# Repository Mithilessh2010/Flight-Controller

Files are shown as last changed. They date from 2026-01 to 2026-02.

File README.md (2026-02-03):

# Rocket Flight Controller

## What This Board Does

This flight controller handles the main electronics:

- Controls servos (for fins or thrust vector control)
- Measures movement and rotation with an IMU
- Measures altitude using a pressure sensor
- Logs flight data to a microSD card
- Uses USB-C for programming and power
- Charges a 2-cell LiPo battery
- Provides stable 5V and 3.3V power

---

## Main Parts Used

- **Microcontroller:** STM32F722RET6  
- **IMU:** ICM-45686 (SPI)  
- **Pressure Sensor:** BMP580 (I2C)  
- **Storage:** microSD card (SDMMC)  
- **Battery Charger:** BQ25883 (2S LiPo)  
- **5V Regulator:** TPS63070  
- **3.3V Regulator:** LMR51430  
- **USB:** USB-C  

---

## Schematics

### Power Section
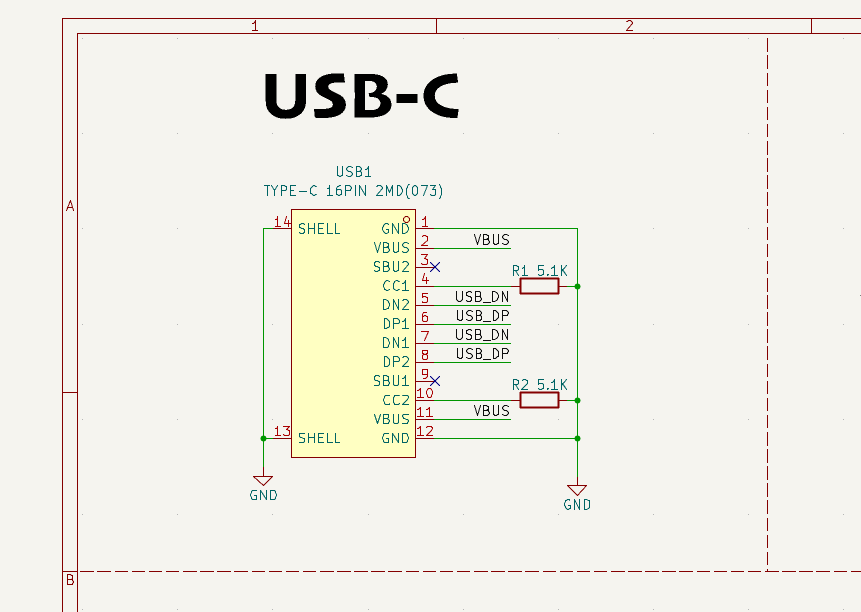
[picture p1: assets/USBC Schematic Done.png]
USB-C

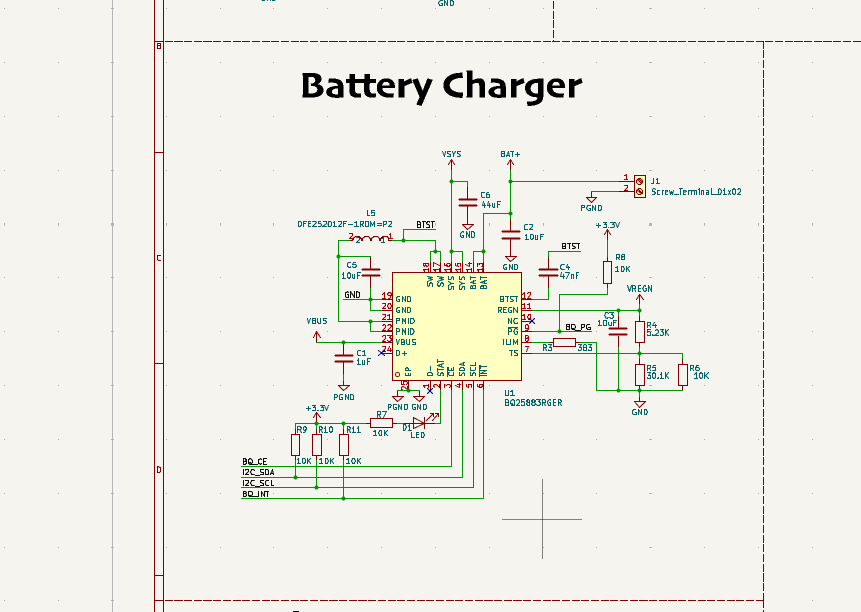
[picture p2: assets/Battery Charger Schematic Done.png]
Battery Charger

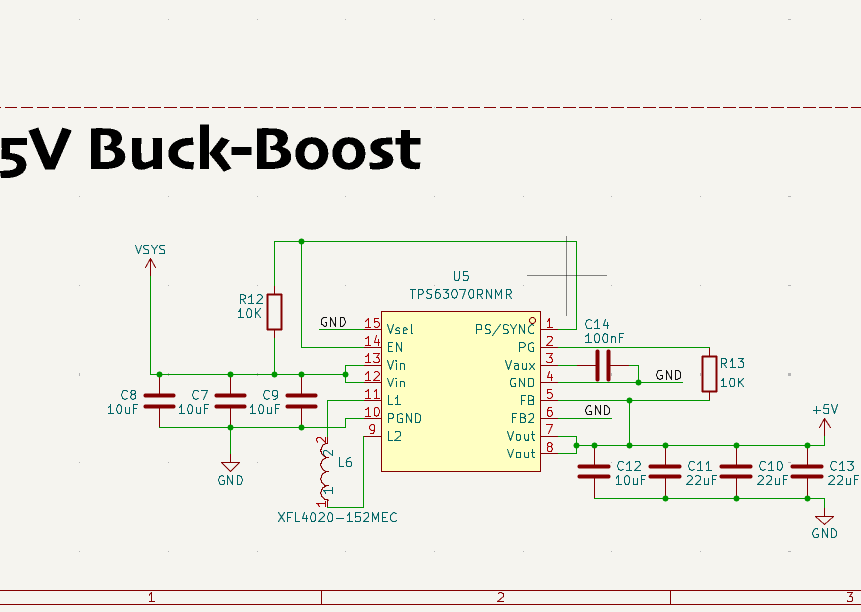
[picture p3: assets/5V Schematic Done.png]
5V Regulator

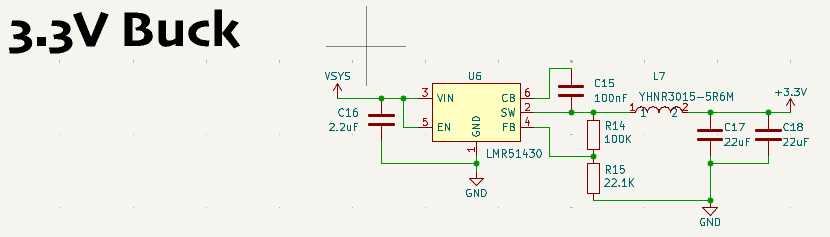
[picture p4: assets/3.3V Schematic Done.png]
3.3V Regulator


### Sensors and Storage
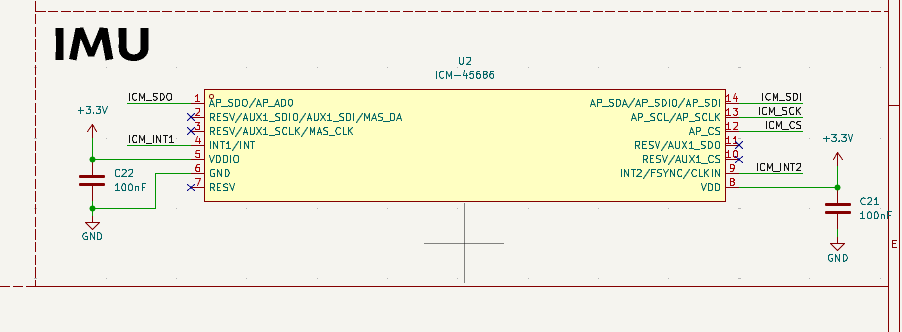
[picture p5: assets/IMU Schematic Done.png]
IMU

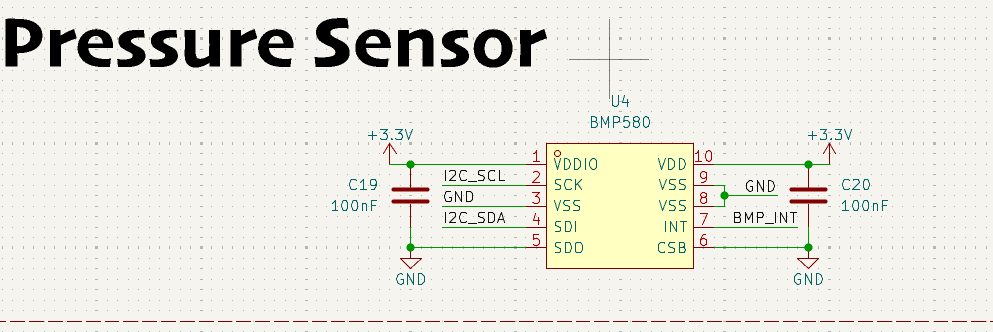
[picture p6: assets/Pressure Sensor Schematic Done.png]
Pressure Sensor

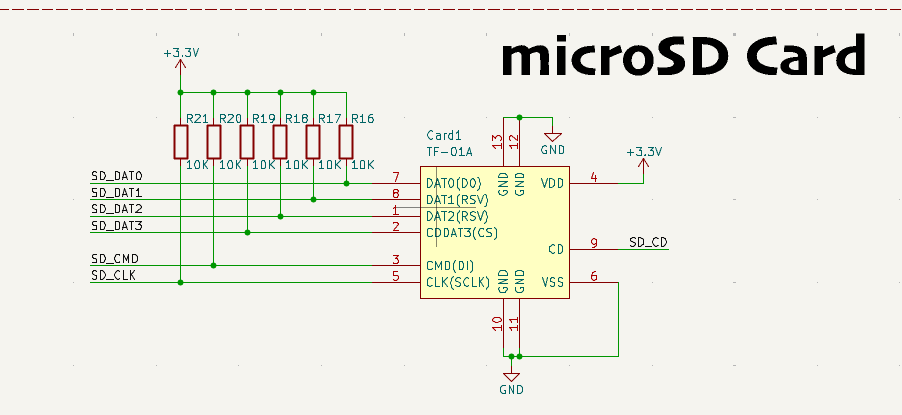
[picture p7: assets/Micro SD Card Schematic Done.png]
MicroSD


---

## Final Design

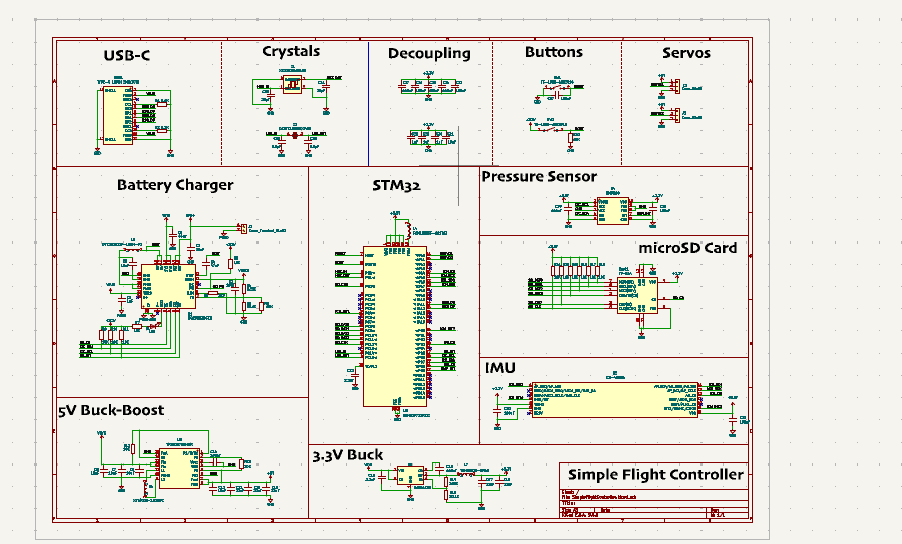
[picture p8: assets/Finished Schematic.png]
Final Schematic

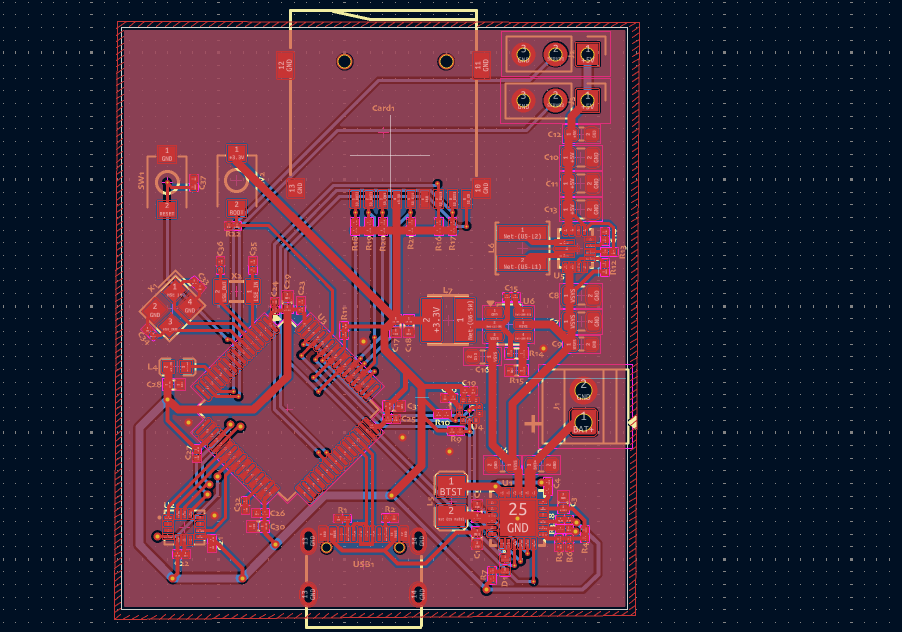
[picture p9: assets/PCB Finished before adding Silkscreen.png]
PCB Before Silkscreen

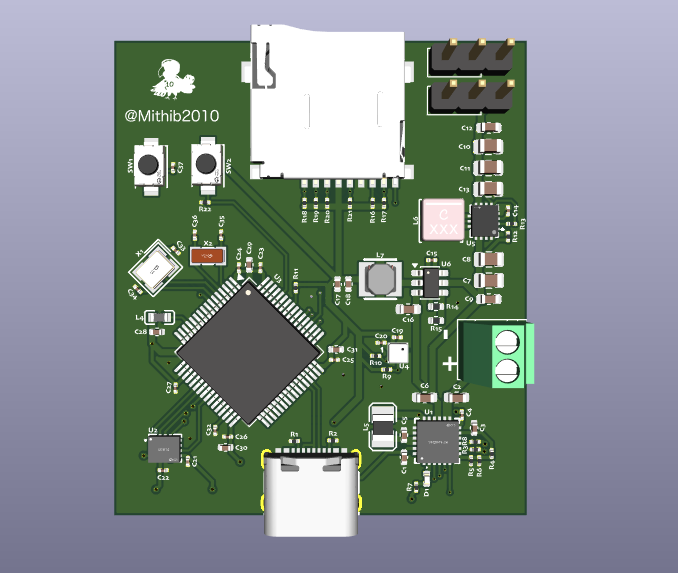
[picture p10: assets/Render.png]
3D Render


---

## Bill of Materials (BOM)

| Part | What it is | Package | Notes |
|----|----|----|----|
| STM32F722RET6 | Main microcontroller | LQFP-64 | Runs all code |
| ICM-45686 | IMU | QFN | Motion sensing |
| BMP580 | Pressure sensor | LGA | Altitude |
| TPS63070 | 5V regulator | QFN | Servo power |
| LMR51430 | 3.3V regulator | SOT | Logic power |
| BQ25883 | 2S battery charger | QFN | USB charging |
| microSD socket | Data storage | SMD | Flight logs |
| USB-C connector | Power + data | SMD | Programming |
| Status LED | Indicator | 0402 | Optional (added) |
| JLCPCB (Total) | The PCBA | PCB | Total: $199 |

---

## PCB and Manufacturing

The PCB was designed in **KiCad**. I paid attention to power routing, grounding, and sensor placement to reduce noise and make the board more reliable.

### JLCPCB

The board was prepared for manufacturing with **JLCPCB**.




- 2-layer PCB  
- Parts chosen from LCSC  
- Designed to be easy to assemble

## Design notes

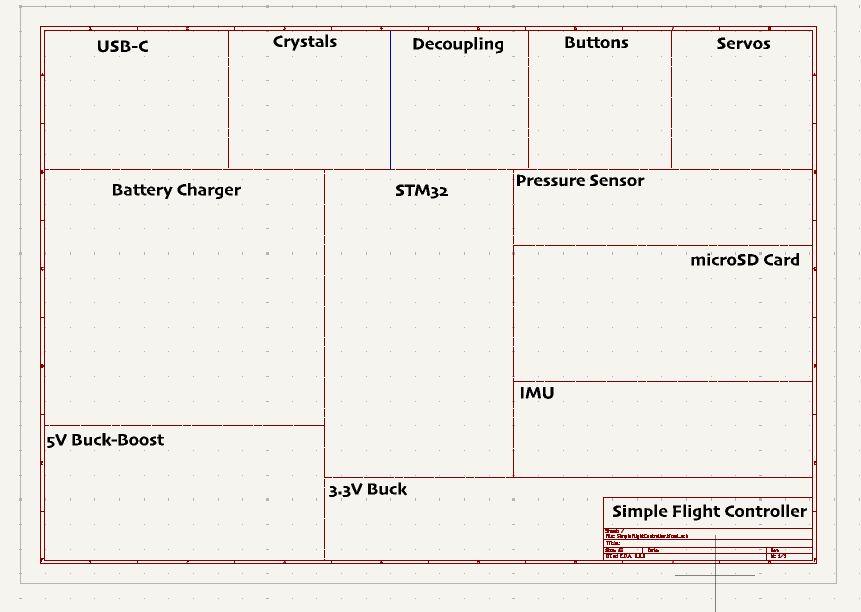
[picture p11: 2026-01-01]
assets/Starting Schematics Format.png

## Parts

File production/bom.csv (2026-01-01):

Designator | Footprint | Quantity | Value | LCSC Part #
BOOT, RESET | SW-SMD_L3.9-W3.0-P4.45 | 2 | TS-1088-AR02016 | C720477
C1, C28, C29, C30 | 0402 | 4 | 1uF
C10, C11, C13 | 0805 | 3 | 22uF
C12, C2, C9 | 0603 | 3 | 10uF
C14, C15, C19, C20, C21, C22, C23, C24, C25, C26, C27, C37 | 0201 | 12 | 100nF
C16 | 0603 | 1 | 2.2uF
C17, C18 | 0402 | 2 | 22uF
C3, C31, C5 | 0402 | 3 | 10uF
C32 | 0201 | 1 | 2.2uF
C33, C34, C35, C36 | 0201 | 4 | 20pF
C4 | 0201 | 1 | 47nF
C6 | 0603 | 1 | 44uF
C7, C8 | 0805 | 2 | 10uF
CARD1 | TF-SMD_TF-01A | 1 | TF-01A | C91145
D1 | 0402 | 1 | LED
J1 | TerminalBlock_Xinya_XY308-2.54-2P_1x02_P2.54mm_Horizontal | 1 | Screw_Terminal_01x02
J2, J3 | PinHeader_1x03_P2.54mm_Vertical | 2 | Conn_01x03
L4 | L0603 | 1 | FCM1608KF-601T03 | C141723
L5 | L2520 | 1 | DFE252012F-1R0M=P2 | C435392
L6 | IND-SMD_L4.0-W4.0-A | 1 | XFL4020-152MEC | C3033018
L7 | IND-SMD_L3.0-W3.0 | 1 | YHNR3015-5R6M | C18236327
R1, R2 | 0201 | 2 | 5.1K
R10, R11, R12, R13, R16, R17, R18, R19, R20, R21, R22, R6, R7, R8, R9 | 0201 | 15 | 10K
R14 | 0402 | 1 | 100K
R15 | 0402 | 1 | 22.1K
R3 | 0201 | 1 | 383
R4 | 0201 | 1 | 5.23K
R5 | 0201 | 1 | 30.1K
U1 | VFQFPN-24_L4.0-W4.0-P0.50-BL-EP2.8 | 1 | BQ25883RGER | C544362
U2 | LGA-14_L3.0-W2.5-P0.50-TL | 1 | ICM-45686 | C22459454
U3 | LQFP-64_10x10mm_P0.5mm | 1 | STM32F722RETx
U4 | LGA-10_L2.0-W2.0-P0.50-TL_BMP580 | 1 | BMP580 | C22391138
U5 | VQFN-HR-15_L3.0-W2.5-P0.50-BL_TPS63070RNMR | 1 | TPS63070RNMR | C109322
U6 | SOT-23-6 | 1 | LMR51430
USB1 | USB-C-SMD_TYPE-C-6PIN-2MD-073 | 1 | TYPE-C 16PIN 2MD(073) | C2765186
X1 | CRYSTAL-SMD_4P-L3.2-W2.5-BL | 1 | X322525MOB4SI | C9006
X2 | FC-135R_L3.2-W1.5 | 1 | Q13FC1350000400 | C32346

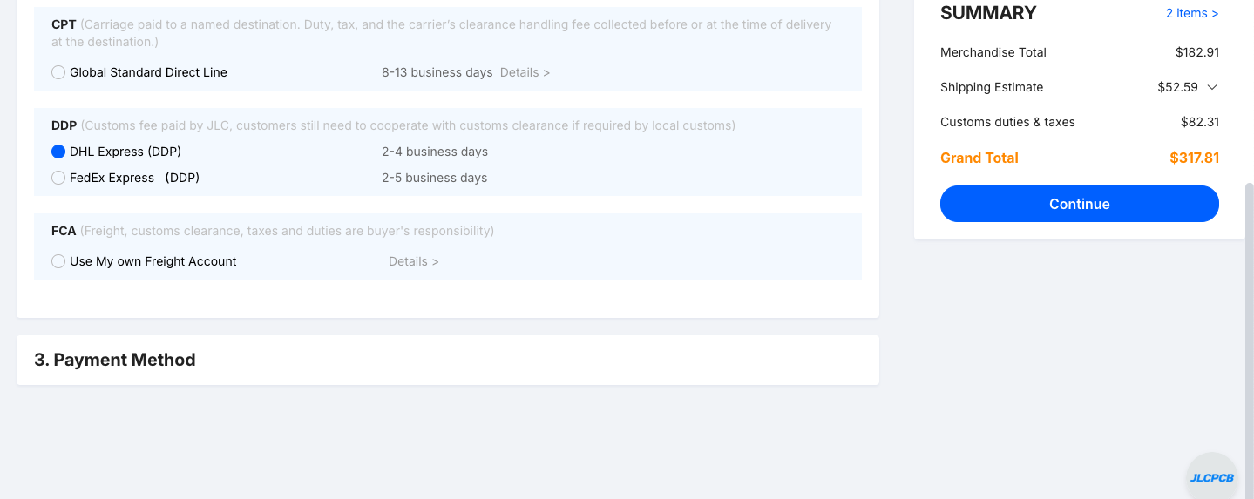
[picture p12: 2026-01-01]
assets/Total Cost.png

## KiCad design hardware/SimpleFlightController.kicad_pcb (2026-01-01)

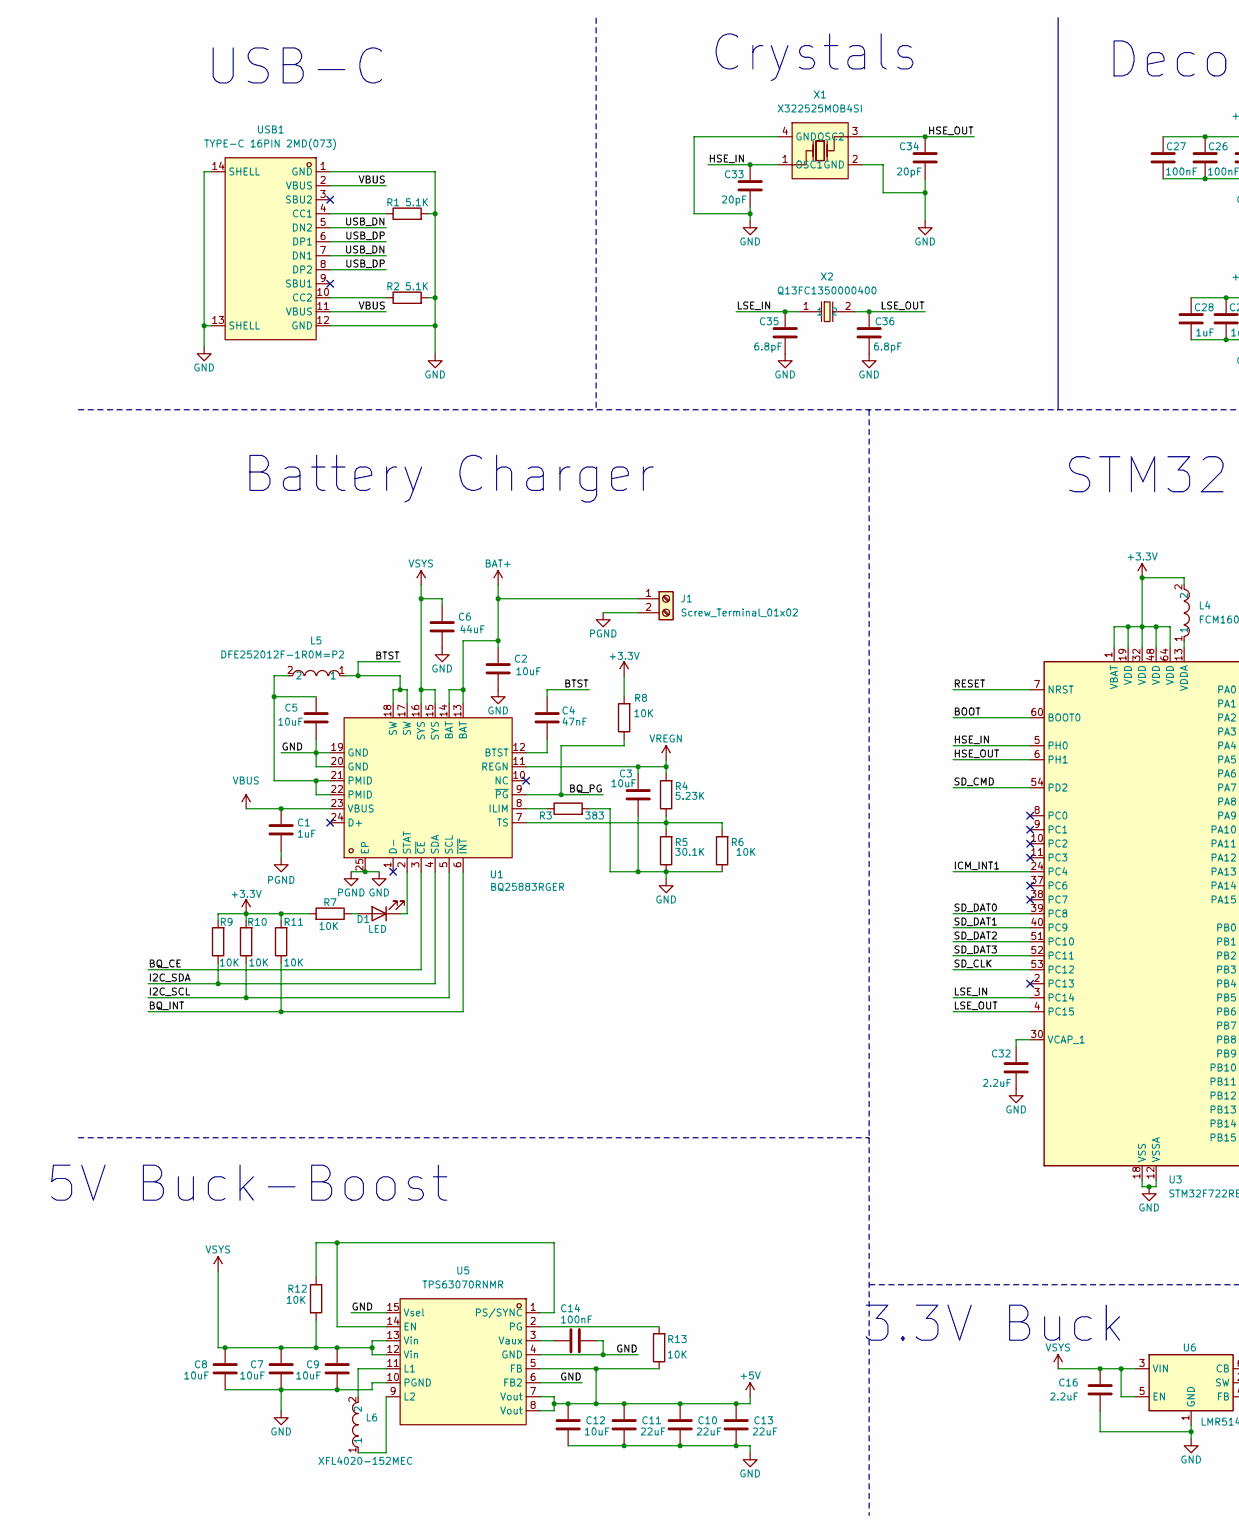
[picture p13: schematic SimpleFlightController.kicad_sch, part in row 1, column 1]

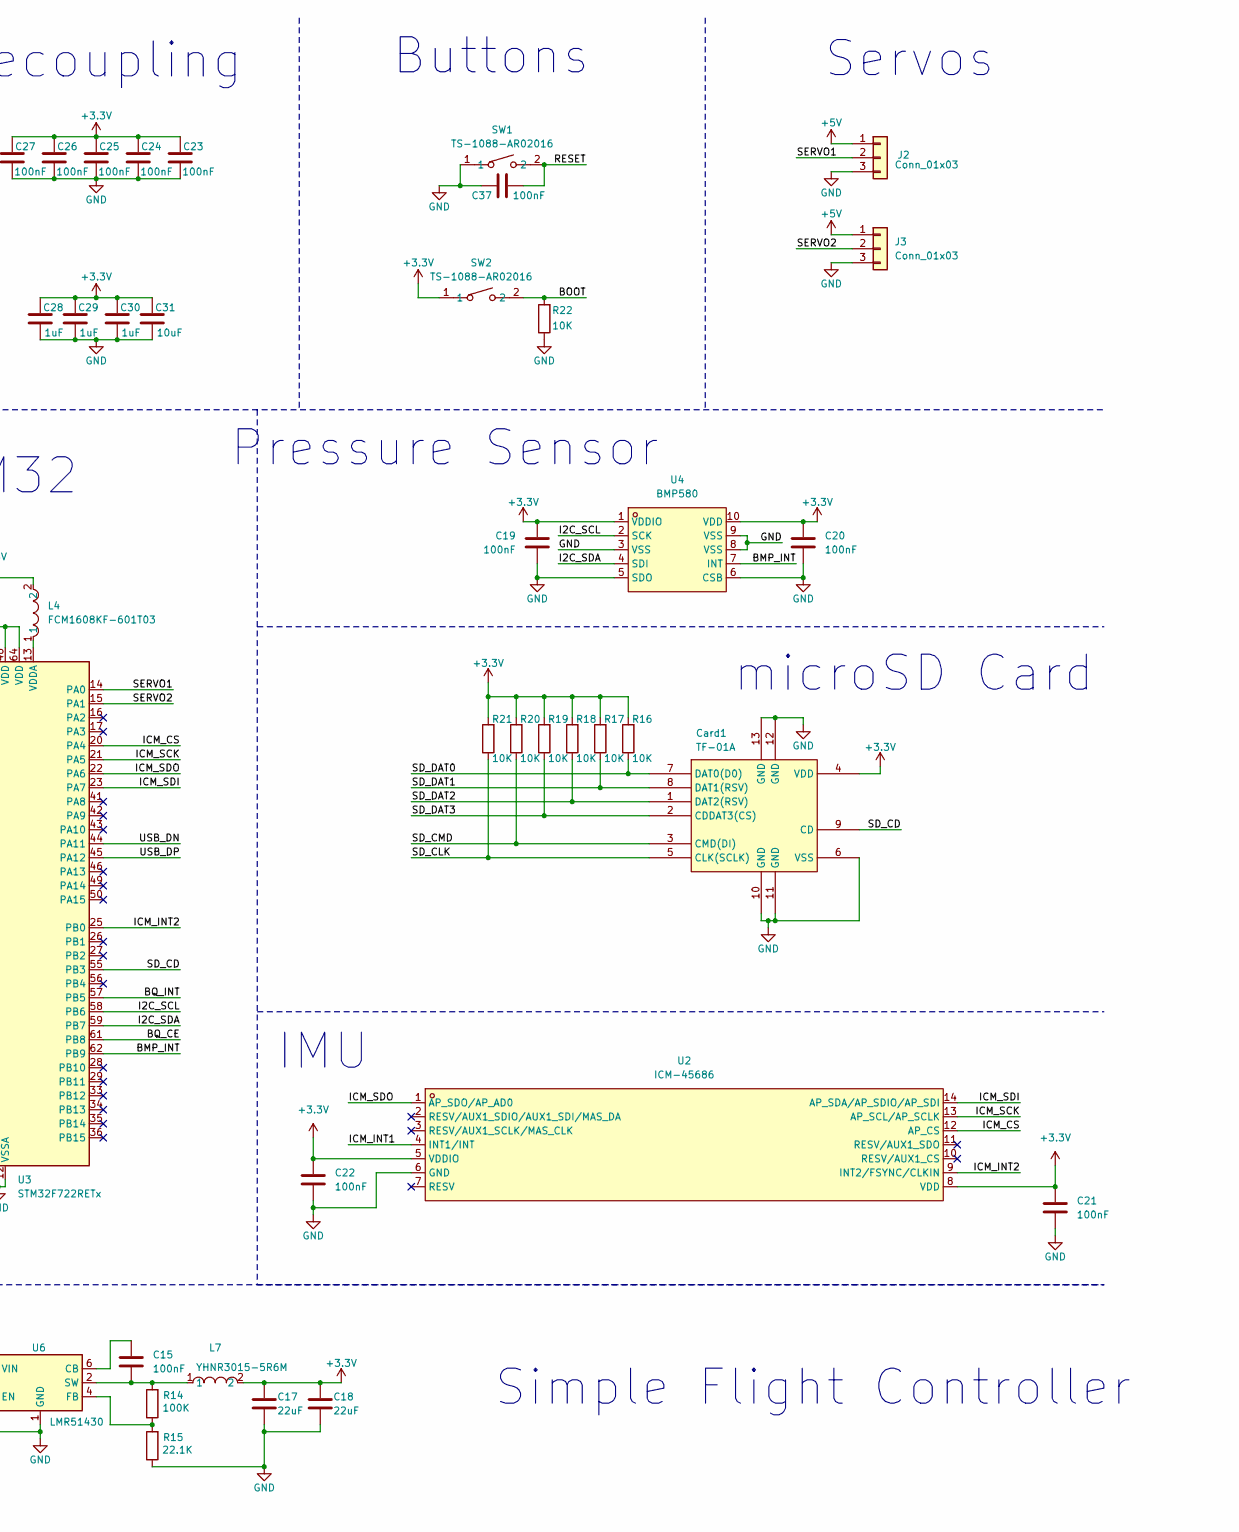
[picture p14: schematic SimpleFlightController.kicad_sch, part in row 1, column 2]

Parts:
C1, C28, C29, C30: 1uF; C_0402_1005Metric
C2, C9, C12: 10uF; C_0603_1608Metric
C3, C5, C31: 10uF; C_0402_1005Metric
C4: 47nF; C_0201_0603Metric
C6: 44uF; C_0603_1608Metric
C7, C8: 10uF; C_0805_2012Metric
C10, C11, C13: 22uF; C_0805_2012Metric
C14, C15, C19, C20, C21, C22, C23, C24, C25, C26, C27, C37: 100nF; C_0201_0603Metric
C16: 2.2uF; C_0603_1608Metric
C17, C18: 22uF; C_0402_1005Metric
C32: 2.2uF; C_0201_0603Metric
C33, C34: 20pF; C_0201_0603Metric
C35, C36: 6.8pF; C_0201_0603Metric
Card1: TF-01A; TF-SMD_TF-01A; LCSC Part C91145
D1: LED; LED_0402_1005Metric
J1: Screw_Terminal_01x02; TerminalBlock_Xinya_XY308-2.54-2P_1x02_P2.54mm_Horizontal
J2, J3: Conn_01x03; PinHeader_1x03_P2.54mm_Vertical
L4: FCM1608KF-601T03; L0603; LCSC Part C141723
L5: DFE252012F-1R0M=P2; L2520; LCSC Part C435392
L6: XFL4020-152MEC; IND-SMD_L4.0-W4.0-A; LCSC Part C3033018
L7: YHNR3015-5R6M; IND-SMD_L3.0-W3.0; LCSC Part C18236327
R1, R2: 5.1K; R_0201_0603Metric
R3: 383; R_0201_0603Metric
R4: 5.23K; R_0201_0603Metric
R5: 30.1K; R_0201_0603Metric
R6, R7, R8, R9, R10, R11, R12, R13, R16, R17, R18, R19, R20, R21, R22: 10K; R_0201_0603Metric
R14: 100K; R_0402_1005Metric
R15: 22.1K; R_0402_1005Metric
SW1, SW2: TS-1088-AR02016; SW-SMD_L3.9-W3.0-P4.45; LCSC Part C720477
U1: BQ25883RGER; VFQFPN-24_L4.0-W4.0-P0.50-BL-EP2.8; LCSC Part C544362
U2: ICM-45686; LGA-14_L3.0-W2.5-P0.50-TL; LCSC Part C22459454
U3: STM32F722RETx; LQFP-64_10x10mm_P0.5mm
U4: BMP580; LGA-10_L2.0-W2.0-P0.50-TL_BMP580; LCSC Part C22391138
U5: TPS63070RNMR; VQFN-HR-15_L3.0-W2.5-P0.50-BL_TPS63070RNMR; LCSC Part C109322
U6: LMR51430; SOT-23-6
USB1: TYPE-C 16PIN 2MD(073); USB-C-SMD_TYPE-C-6PIN-2MD-073; LCSC Part C2765186
X1: X322525MOB4SI; CRYSTAL-SMD_4P-L3.2-W2.5-BL; LCSC Part C9006
X2: Q13FC1350000400; FC-135R_L3.2-W1.5; LCSC Part C32346

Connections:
+3.3V: C17.1, C18.1, C19.1, C20.1, C21.1, C22.1, C23.1, C24.1, C25.1, C26.1, C27.1, C28.1, C29.1, C30.1, C31.1, Card1.4 (VDD), L4.2, L7.2, R7.2, R8.2, R9.2, R10.2, R11.2, R16.2, R17.2, R18.2, R19.2, R20.2, R21.2, SW2.1, U2.5 (VDDIO), U2.8 (VDD), U3.1 (VBAT), U3.19 (VDD), U3.32 (VDD), U3.48 (VDD), U3.64 (VDD), U4.1 (VDDIO), U4.10 (VDD)
+5V: C10.1, C11.1, C12.1, C13.1, J2.1, J3.1, R13.1, U5.5 (FB), U5.7 (Vout), U5.8 (Vout)
/BMP_INT: U3.62 (PB9), U4.7 (INT)
/BOOT: R22.2, SW2.2, U3.60 (BOOT0)
/BQ_CE: U1.3 (~CE), U3.61 (PB8)
/BQ_INT: R11.1, U1.6 (~INT), U3.57 (PB5)
/BQ_PG: R8.1, U1.9 (~PG)
/BTST: C4.1, L5.1, U1.17 (SW), U1.18 (SW)
/HSE_IN: C33.1, U3.5 (PH0), X1.1 (OSC1)
/HSE_OUT: C34.1, U3.6 (PH1), X1.3 (OSC2)
/I2C_SCL: R10.1, U1.5 (SCL), U3.58 (PB6), U4.2 (SCK)
/I2C_SDA: R9.1, U1.4 (SDA), U3.59 (PB7), U4.4 (SDI)
/ICM_CS: U2.12 (AP_CS), U3.20 (PA4)
/ICM_INT1: U2.4 (INT1/INT), U3.24 (PC4)
/ICM_INT2: U2.9 (INT2/FSYNC/CLKIN), U3.25 (PB0)
/ICM_SCK: U2.13 (AP_SCL/AP_SCLK), U3.21 (PA5)
/ICM_SDI: U2.14 (AP_SDA/AP_SDIO/AP_SDI), U3.23 (PA7)
/ICM_SDO: U2.1 (AP_SDO/AP_AD0), U3.22 (PA6)
/LSE_IN: C35.1, U3.3 (PC14), X2.1
/LSE_OUT: C36.1, U3.4 (PC15), X2.2
/RESET: C37.2, SW1.2, U3.7 (NRST)
/SD_CD: Card1.9 (CD), U3.55 (PB3)
/SD_CLK: Card1.5 (CLK(SCLK)), R21.1, U3.53 (PC12)
/SD_CMD: Card1.3 (CMD(DI)), R20.1, U3.54 (PD2)
/SD_DAT0: Card1.7 (DAT0(D0)), R16.1, U3.39 (PC8)
/SD_DAT1: Card1.8 (DAT1(RSV)), R17.1, U3.40 (PC9)
/SD_DAT2: Card1.1 (DAT2(RSV)), R18.1, U3.51 (PC10)
/SD_DAT3: Card1.2 (CDDAT3(CS)), R19.1, U3.52 (PC11)
/SERVO1: J2.2, U3.14 (PA0)
/SERVO2: J3.2, U3.15 (PA1)
/USB_DN: U3.44 (PA11), USB1.5 (DN2), USB1.7 (DN1)
/USB_DP: U3.45 (PA12), USB1.6 (DP1), USB1.8 (DP2)
BAT+: C2.1, J1.1, U1.13 (BAT), U1.14 (BAT)
GND: C1.2, C2.2, C3.2, C5.2, C6.2, C7.2, C8.2, C9.2, C10.2, C11.2, C12.2, C13.2, C14.2, C16.2, C17.2, C18.2, C19.2, C20.2, C21.2, C22.2, C23.2, C24.2, C25.2, C26.2, C27.2, C28.2, C29.2, C30.2, C31.2, C32.2, C33.2, C34.2, C35.2, C36.2, C37.1, Card1.6 (VSS), Card1.10 (GND), Card1.11 (GND), Card1.12 (GND), Card1.13 (GND), J1.2, J2.3, J3.3, R1.2, R2.2, R3.2, R5.1, R6.1, R15.1, R22.1, SW1.1, U1.19 (GND), U1.20 (GND), U1.25 (EP), U2.6 (GND), U3.12 (VSSA), U3.18 (VSS), U3.31 (VSS), U3.47 (VSS), U3.63 (VSS), U4.3 (VSS), U4.5 (SDO), U4.6 (CSB), U4.8 (VSS), U4.9 (VSS), U5.4 (GND), U5.6 (FB2), U5.10 (PGND), U5.15 (Vsel), U6.1 (GND), USB1.1 (GND), USB1.12 (GND), USB1.13 (SHELL), USB1.14 (SHELL), X1.2 (GND), X1.4 (GND)
unnamed: C5.1, L5.2, U1.21 (PMID), U1.22 (PMID)
unnamed: D1.2 (A), R7.1
unnamed: D1.1 (K), U1.2 (STAT)
unnamed: C4.2, U1.12 (BTST)
unnamed: R3.1, U1.8 (ILIM)
unnamed: R4.1, R5.2, R6.2, U1.7 (TS)
unnamed: C32.1, U3.30 (VCAP_1)
unnamed: L4.1, U3.13 (VDDA)
unnamed: R12.1, U5.1 (PS/SYNC), U5.14 (EN)
unnamed: L6.2, U5.11 (L1)
unnamed: L6.1, U5.9 (L2)
unnamed: R13.2, U5.2 (PG)
unnamed: C14.1, U5.3 (Vaux)
unnamed: C15.1, U6.6 (CB)
unnamed: R14.1, R15.2, U6.4 (FB)
unnamed: C15.2, L7.1, R14.2, U6.2 (SW)
unnamed: R1.1, USB1.4 (CC1)
unnamed: R2.1, USB1.10 (CC2)
VBUS: C1.1, U1.23 (VBUS), USB1.2 (VBUS), USB1.11 (VBUS)
VREGN: C3.1, R4.2, U1.11 (REGN)
VSYS: C6.1, C7.1, C8.1, C9.1, C16.1, R12.2, U1.15 (SYS), U1.16 (SYS), U5.12 (Vin), U5.13 (Vin), U6.3 (VIN), U6.5 (EN)

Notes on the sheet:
Simple Flight Controller
Pressure Sensor
Decoupling
3.3V Buck
Buttons
IMU
USB-C
Servos
Battery Charger
STM32
Crystals
microSD Card
5V Buck-Boost

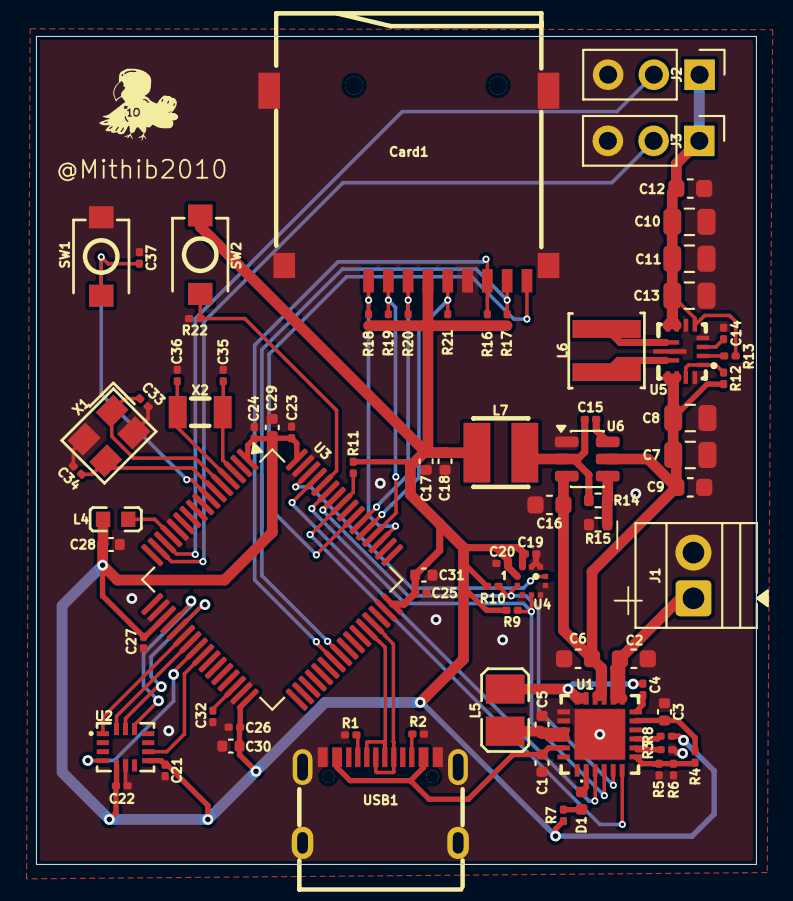
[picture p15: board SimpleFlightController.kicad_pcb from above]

Board: 2 copper layers, 40.0 x 46.0 mm, 79 parts (0 on the bottom side), 55 nets.

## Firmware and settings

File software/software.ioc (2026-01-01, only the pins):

Mcu.UserName=STM32F722RETx
PA0-WKUP.Signal=S_TIM2_CH1_ETR
PA1.Signal=S_TIM2_CH2
PA11.Signal=USB_OTG_FS_DM
PA12.Signal=USB_OTG_FS_DP
PA4.Signal=SPI1_NSS
PA5.Signal=SPI1_SCK
PA6.Signal=SPI1_MISO
PA7.Signal=SPI1_MOSI
PB0.GPIO_Label=ICM_INT2
PB0.Signal=GPXTI0
PB3.GPIO_Label=SD_CS
PB3.Signal=GPIO_Input
PB5.GPIO_Label=BQ_INT
PB5.Signal=GPXTI5
PB6.Signal=I2C1_SCL
PB7.Signal=I2C1_SDA
PB8.GPIO_Label=BQ_CE
PB8.Signal=GPIO_Output
PB9.GPIO_Label=BMP_INT
PB9.Signal=GPXTI9
PC10.Signal=SDMMC1_D2
PC11.Signal=SDMMC1_D3
PC12.Signal=SDMMC1_CK
PC14-OSC32_IN.Signal=RCC_OSC32_IN
PC15-OSC32_OUT.Signal=RCC_OSC32_OUT
PC4.GPIO_Label=ICM_INT1
PC4.Signal=GPXTI4
PC8.Signal=SDMMC1_D0
PC9.Signal=SDMMC1_D1
PD2.Signal=SDMMC1_CMD
PH0-OSC_IN.Signal=RCC_OSC_IN
PH1-OSC_OUT.Signal=RCC_OSC_OUT
